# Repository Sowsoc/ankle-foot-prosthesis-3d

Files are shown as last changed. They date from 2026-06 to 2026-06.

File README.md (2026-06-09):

# Prótese funcional de pé-tornozelo articulada (impressa em 3D, baixo custo)

**Disciplina:** Dispositivos de Reabilitação — Eng. Biomédica, FUMEC
**Entrega:** 22/06/2026 — produto físico + relatório técnico + apresentação formal
**Natureza:** trabalho dedicado e independente

---

## Decisões de projeto (travadas em 06/06)

| Eixo | Decisão | Razão |
|---|---|---|
| Origem do design | **Remixar open-source** | Prazo de 16 dias; partir de base comprovada e justificar mudanças é mais defensável que do zero |
| **Design-base** | **A — Make3D "Prosthetic Foot Prototype" (Printables #293133)** | Votado pelo grupo em 08/06; maior score (4,2/5), single-axis direto, conector de pylon integrado. Arquivos em `cad/A_make3d_293133/` |
| **Conector de pylon** | **Insert custom do design-base (Opção A)** | Votado pelo grupo em 09/06; conector retangular 26×14×46 mm integrado ao modelo — adequado para demonstração acadêmica, sem peça comprada extra |
| Alvo dimensional | **Genérico adulto padrão** | Sem dependência de medir paciente; protótipo demonstrativo |
| Articulação | **Single-axis (dorsi/plantarflexão)** | Mais simples de modelar e imprimir; clássico e suficiente para "funcional" |
| Régua de avaliação | **Briefing livre → régua proposta abaixo** | Não há enunciado escrito do professor |

---

## Requisitos / especificações alvo

Usuário de projeto: **adulto ~70 kg, pé ~26–27 cm (BR 40–41)**.

| Requisito | Valor alvo | Observação |
|---|---|---|
| Carga estática de projeto | ≥ 1,5 × peso corporal ≈ **1030 N** | Pico de heel-strike na marcha normal é ~1,2–1,5× BW |
| Fator de segurança | **2–3** → dimensionar p/ ~2–3 kN | Literatura: FEA achou tensão máx. **15 MPa no heel-strike a 150% BW** |
| ADM dorsiflexão | **10–15°** | Limitada por batente elástico anterior |
| ADM plantarflexão | **15–20°** | Limitada por batente elástico posterior |
| Conexão proximal | Adaptador de pylon padrão (pirâmide 30 mm) ou simplificado | Depende do que o design-base oferece |
| Custo de material | **< R$ 200** | Filamento + parafuso/bucha + TPU. Comparar com prótese comercial (US$ 5k–50k) |
| Massa | minimizar (alvo informativo) | Trade-off com rigidez |

### Materiais previstos
- **Estrutura/keel:** PETG (tenaz, melhor fadiga/impacto que PLA) ou PLA-CF (mais rígido). **Evitar PLA puro** sob carga cíclica — frágil, falha por fadiga.
- **Eixo da articulação:** parafuso de aço M8 + bucha (nylon/bronze).
- **Batentes (bumpers) dorsi/plantar:** TPU ~95A — definem a ADM e amortecem.
- **Orientação de impressão (CRÍTICO):** carga principal deve solicitar o **mínimo possível** a adesão entre camadas (eixo Z é o ponto fraco do FDM). Imprimir o keel deitado.

---

## Régua de avaliação (proposta — briefing livre)

Como não há enunciado, esta é a régua que vou usar para guiar o relatório/apresentação. Ajuste se o professor sinalizar critério diferente.

1. **Produto físico funcional** — articulação se move na ADM alvo e suporta a carga de demonstração. *(peso maior)*
2. **Relatório técnico completo** — ver `RELATORIO.md`.
3. **Fundamentação biomecânica** — ciclo de marcha, papel do tornozelo, justificativa da articulação single-axis vs SACH.
4. **Justificativa de engenharia** — escolha de material, orientação de impressão, geometria, com trade-offs explícitos.
5. **Validação** — teste de ADM medido, teste de carga (mesmo qualitativo), fotos/vídeo. Ver `testes/`.
6. **Baixo custo demonstrado** — planilha de custo real vs. alternativa comercial.
7. **Apresentação formal** — domínio do tema, defesa dos trade-offs sob arguição.

---

## Candidatos open-source para remixar

| Candidato | Articulação | Prós | Contras |
|---|---|---|---|
| **Make3D "Prosthetic Foot Prototype"** (Printables 293133) | Pino + mola, dedos flexíveis, conector de pylon | Match mais direto; STL grátis; feito em Fusion 360 (editável) | **Não testado**; usa Filaflex40 + mola |
| **Appropedia "3D printed prosthetic foot"** | Snap-fit + amortecedor ball-joint | Open source de verdade; ~4% do custo comercial; simples | Estágio "infância"; pouca validação |
| **Colorado School of Mines Capstone** | Flex-ankle (dobradiça flexível), passivo | Pensado p/ ABS / PETG-nylon; manual de instruções | Pediátrico; precisa reescalar |

**Recomendação:** começar pela **Make3D (Printables)** como base estrutural single-axis e simplificar a mola para batentes TPU (mais imprimível, menos dependência de peça comprada). Baixar o STL/CAD para `cad/` e `refs/`.

Referências acadêmicas para fundamentar o relatório (salvar PDFs em `refs/`):
- Baseline não-articulado: **SACH** (solid-ankle cushion-heel) — comparar contra ele.
- FEA de pé protético: tensão máx. 15 MPa @ 150% BW; recurso de projeto = **split forefoot/heel**.
- Toe joint com rigidez não-linear (Nature Sci. Reports) — se for modelar antepé flexível.
- Composites: PLA/fibra de carbono supera PLA puro em desempenho/peso.

Links em `refs/FONTES.md`.

---

## Riscos (ordem de severidade)

1. **Acesso à impressora 3D** — gargalo absoluto. Um pé inteiro são muitas horas/peça + chance de falha. *Se depende do lab da FUMEC, agendar AGORA.* ⛔ bloqueante.
2. **Falha estrutural por orientação/material** — camada Z fraca. Mitigação: PETG, orientação correta, infill 40%+, parede grossa.
3. **Colisão com o estágio (início 15/06)** — janela de impressão encolhe. Travar CAD até 14/06.
4. **Articulação (pino/folga/batente)** — ponto de movimento = ponto de desgaste/folga. Prototipar a junta isolada antes da peça inteira.

---

## Estrutura de pastas

- `cad/` — arquivos editáveis (Fusion/FreeCAD/STEP)
- `stl/` — malhas prontas para fatiar
- `slicing/` — perfis e .gcode/.3mf, parâmetros de impressão
- `refs/` — design-base baixado, PDFs de referência, `FONTES.md`
- `fotos/` — registro de fabricação/montagem/testes (para o relatório)
- `testes/` — dados de ADM e carga, planilha de custo
- `RELATORIO.md` — relatório técnico (em construção)
- `PLANO.md` — cronograma de 16 dias e caminho crítico

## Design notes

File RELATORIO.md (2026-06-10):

# Relatório técnico — Prótese funcional de pé-tornozelo articulada (3D, baixo custo)

> Disciplina: Dispositivos de Reabilitação — FUMEC · Autor: João Vítor Silva Oliveira · Entrega: 22/06/2026
> Esqueleto. Cada seção lista o que precisa conter. `[ ]` = a preencher. As decisões de
> engenharia, o CAD e a validação são trabalho seu — este arquivo é o mapa, não o conteúdo.

## Resumo (abstract)
- [ ] 1 parágrafo: o que é, decisão single-axis, material, custo, principal resultado de validação.

## 1. Introdução

### 1.1 Problema

A amputação de membro inferior impõe ao indivíduo a dependência de uma prótese para restaurar a marcha. O componente pé-tornozelo é determinante para a qualidade dessa marcha — é ele que faz o contato com o solo, absorve o impacto do heel-strike e devolve energia no push-off. Próteses de pé-tornozelo comerciais funcionais, contudo, custam tipicamente de **US$ 5.000 a US$ 50.000** [MDPI Machines 10(6):413], valor proibitivo em contextos de baixa renda e sistemas públicos de saúde sobrecarregados. O resultado é um déficit global de acesso: a OMS estima que apenas uma fração das pessoas que necessitam de próteses tem acesso a elas.

A manufatura aditiva (impressão 3D FDM) abriu uma via para reduzir radicalmente esse custo. Designs open-source de pés protéticos imprimíveis relatam custo de material em torno de **4 % do equivalente comercial** [Appropedia; MDPI Machines 10(6):413], ao preço de menor validação estrutural e durabilidade. O desafio de engenharia é claro: entregar mobilidade de tornozelo e resistência estrutural suficientes com filamento de baixo custo e um processo (FDM) intrinsecamente anisotrópico.

### 1.2 Distinção prótese × órtese

Convém fixar o termo, dado que a disciplina trata dos dois dispositivos. **Órtese** é um dispositivo que *assiste ou corrige* um segmento corporal existente (ex.: uma AFO — ankle-foot orthosis — que apoia um tornozelo fraco). **Prótese** *substitui* um segmento ausente. Este trabalho é uma **prótese**: substitui o pé-tornozelo de um amputado, não auxilia um membro presente.

### 1.3 Objetivo e escopo

O objetivo é projetar, fabricar e validar um **protótipo funcional de pé-tornozelo protético articulado**, impresso em 3D (FDM) a baixo custo, com mobilidade real de tornozelo (mecanismo single-axis), partindo do remix de um design open-source e justificando cada decisão de engenharia.

**Escopo e fronteiras:**
- Trata-se do **módulo pé-tornozelo** de uma prótese **transtibial** (abaixo do joelho) modular. O encaixe (cartucho moldado ao coto, paciente-específico) e o pylon (tubo padronizado) são componentes *upstream* fora do escopo — o projeto entrega a peça que se conecta ao pylon.
- Usuário de projeto genérico: adulto ~70 kg, pé 26-27 cm (BR 40-41), **marcha em superfície plana**. Corrida e terreno irregular estão fora do escopo.
- **Dispositivo de demonstração acadêmica — não clínico.** Nenhum protótipo deste trabalho deve receber carga corporal real sem validação mecânica formal (ensaio de fadiga/ciclagem) e avaliação de protético certificado. A validação aqui é qualitativa/demonstrativa (amplitude de movimento e teste de carga estática), não uma certificação de uso.

### 1.4 Organização do relatório

A seção 2 fundamenta a biomecânica do tornozelo na marcha e as cargas de projeto; a seção 3 fecha os requisitos de engenharia; a seção 4 descreve a concepção e as alterações sobre o design-base; a seção 5 trata de materiais, dimensionamento estrutural e fabricação; as seções 6 a 8 apresentam a validação, o custo e a discussão; a seção 9 conclui.

## 2. Fundamentação biomecânica

### 2.1 Ciclo da marcha e papel do tornozelo

O ciclo da marcha divide-se em fase de apoio (stance, ~60% do ciclo) e fase de balanço (swing, ~40%). O tornozelo cumpre três funções biomecânicas críticas durante o apoio [PMC4994968]:

1. **Heel-strike / loading response (0–12% do ciclo):** ao toque do calcanhar, a GRF impõe carga de impacto. O tornozelo entra em plantarflexão rápida (~5–10°) enquanto os dorsiflexores (tibial anterior) desaceleram o pé. Este é o pico de carga estrutural sobre a prótese.

2. **Midstance (10–30%):** o corpo avança sobre o pé fixo; o tornozelo funciona como pivot. GRF vertical ≈ 1,0–1,2 × PC.

3. **Push-off / toe-off (40–60%):** plantarflexão ativa (~20°) pelo tríceps sural impulsiona o corpo para frente. Em prótese passiva, batentes elásticos (TPU) absorvem parte da energia de retorno.

### 2.2 Amplitude de movimento fisiológica na marcha

| Movimento | Valor fisiológico | Alvo do protótipo |
|---|---|---|
| Dorsiflexão | 10–15° [1] | 10–15° — batente anterior TPU |
| Plantarflexão | 15–20° [1] | 15–20° — batente posterior TPU |
| ADM total sagital na marcha | ~25–35° [1] | 25–35° |

[1] Síntese de: OrthoFixar — Ankle Range of Motion; Meloq Devices — Normal Ankle ROM; Biomechanics of the ankle — PMC4994968.

### 2.3 Por que articular: SACH vs. single-axis

A prótese SACH (solid-ankle cushion-heel) é o baseline não-articulado mais difundido — baixo custo, zero manutenção, mas sem mobilidade real de tornozelo:

| Critério | SACH | Single-axis (este projeto) |
|---|---|---|
| ADM | 0° (rígida) | 10–15° dorsi / 15–20° plantar |
| Absorção de choque | calcanhar em espuma | batente TPU dorsal absorve heel-strike |
| Adaptação a terreno | limitada | parcial — ADM absorve variação de inclinação |
| Custo / complexidade | mínimos | baixo — eixo M8 + batentes TPU |

A articulação single-axis é a escolha mínima viável que confere mobilidade real sem a complexidade de sistemas multi-eixo ou ESAR (energy-storing-and-return em carbono), inviáveis no prazo e custo deste projeto.

### 2.4 Cargas na seção crítica (heel-strike)

GRF vertical de pico na marcha normal: **1,0–1,5 × PC** [Nilsson & Thorstensson, Acta Physiol Scand 1989, PMID 2782094]. Para o usuário de projeto (70 kg):

- **Carga de projeto: P = 1,5 × 70 × 9,81 ≈ 1030 N** (extremo conservador da marcha plana)
- Referência de sanidade: FEA de pé protético acha tensão máx. ~15 MPa no heel-strike a 150% PC [ResearchGate 318989655] — mesma ordem do dimensionamento preliminar (ver seção 5).
- Escopo: marcha em superfície plana. Corrida (pico 2,0–2,9 × PC) está fora do escopo deste protótipo acadêmico.

## 3. Requisitos de projeto

**Usuário de projeto:** adulto genérico, ~70 kg, pé 26–27 cm (BR 40–41), marcha em superfície plana.

| Requisito | Valor alvo | Justificativa |
|---|---|---|
| Carga estática de projeto | ≥ 1030 N (= 1,5 × BW) | GRF de pico na marcha normal é 1,0–1,5 × BW [Nilsson & Thorstensson, PMID 2782094]; extremo superior = conservador |
| Fator de segurança | 2–3 (FS = 2,5 adotado) | Faixa padrão para dispositivos com carga dinâmica e fabricação FDM (variabilidade de processo elevada) |
| ADM dorsiflexão | 10–15° | Mínimo para marcha eficiente sem compensação proximal [PMC4994968]; definida por batente TPU anterior |
| ADM plantarflexão | 15–20° | Necessário para push-off e descida [PMC4994968]; definida por batente TPU posterior |
| Conexão proximal | Adaptador pylon pirâmide 30 mm ou simplificado | Padrão ISO 22523; depende do design-base escolhido |
| Custo de material | < R$ 200 | PETG (~250 g × R$ 120/kg ≈ R$ 30) + TPU + M8 + bucha; comparar com SACH comercial (US$ 5k–50k) |
| Massa | minimizar (alvo informativo) | Trade-off com rigidez; aceito no escopo acadêmico |
| Material estrutural | PETG (keel) + TPU ~95A (batentes) + M8 aço 8.8 (eixo) | Justificativa completa em seção 5 e `testes/dimensionamento.py` |
| Orientação de impressão | Keel deitado (carga no plano XY) | Anisotropia Z do FDM reduz resistência 30–50% [OSTI 1808415]; orientar para máxima resistência no plano — ver seção 5 |

## 4. Concepção e projeto (design)

### 4.1 Estratégia: remix de design open-source

Dado o prazo de 16 dias e a régua de "produto funcional defensável", optou-se por **remixar um design open-source comprovado** em vez de modelar do zero. Partir de uma base existente e justificar cada alteração de engenharia é mais defensável — e mais honesto sobre o esforço real — do que reivindicar um projeto original mal validado.

O design-base foi selecionado por matriz de decisão ponderada (ver `refs/decisao_design_base.md`), com critérios de imprimibilidade FDM, robustez, facilidade de edição, aderência ao mecanismo single-axis e licença. Venceu o **Make3D "Prosthetic Foot Prototype"** (Printables #293133, licença CC BY-NC-SA), com score 4,2/5, por oferecer articulação single-axis direta, conector de pylon integrado e a maior comunidade de remix.

**Limitação assumida:** o autor publicou apenas malhas STL — não há arquivo CAD paramétrico (Fusion 360/STEP) oficial. A adaptação foi feita, portanto, por **edição de malha** (script reproduzível em `cad/A_make3d_293133/processar_pecas.py`, biblioteca `trimesh`), e não por modelagem paramétrica. Isso restringe o tipo de alteração possível (escala e operações booleanas, não re-parametrização de features), mas é suficiente para as três mudanças que o projeto exige.

### 4.2 Componentes do design-base e papéis

| Peça (STL nativo) | Papel | Material no remix |
|---|---|---|
| `InnerFoot` | Keel — quilha estrutural; carrega a flexão do heel-strike | PETG |
| `TopJoint` | Junta superior do tornozelo; aloja o eixo de pivô | PETG |
| `FootRubber` | Sola / antepé flexível | TPU 95A |
| `RubberCube` | Batente elástico (define a ADM e amortece) | TPU 95A |
| `Insert` | Conector proximal ao pylon | PETG |

> **Escopo:** este trabalho desenvolve o **módulo pé-tornozelo** de uma prótese **transtibial** modular. O encaixe (cartucho moldado ao coto, paciente-específico) e o pylon (tubo padronizado) são componentes *upstream* fora do escopo — representados apenas em diagrama. O `Insert` é a interface física com o pylon.

### 4.3 Alterações de engenharia (o que mudou e por quê)

Três modificações sobre o design-base, todas defensáveis:

**1. Escala ×1,262 do casco (pé ~21 cm → 26-27 cm).**
O modelo nativo tem pé de 209,9 mm (≈ BR 33), abaixo do usuário de projeto (adulto, pé 26-27 cm, BR 40-41). Aplicou-se escala uniforme de 1,262 às peças do casco (keel, sola, conector, batente). O `TopJoint` foi **mantido em escala nativa** (ver alteração 2). A escala, além de atender ao requisito dimensional, **reduz a tensão estrutural**: como σ_flexão ∝ (P·L)/(B·H²), escalar todas as dimensões por *s* faz σ variar com 1/*s²* — escalar para o alvo melhora a margem em ~37 % (ver seção 5 e `testes/dimensionamento.py`).

**2. Normalização do eixo da articulação para M8.**
O design nativo usa dois diâmetros distintos no mesmo eixo de pivô: furo Ø4,8 mm (≈ passagem de M5) no keel e bore Ø10,0 mm no `TopJoint`. Nenhum corresponde ao eixo M8 8.8 dimensionado na seção 5. A solução:
- **Keel:** furo aberto de Ø4,8 → **Ø8,4 mm** (folga de M8), via operação booleana concêntrica ao eixo nativo.
- **TopJoint mantido nativo:** o bore Ø10,0 mm casa **exatamente** com uma **bucha de nylon comercial 10×8** (OD 10 / ID 8). Manter o `TopJoint` sem escala preserva esse encaixe de prateleira — escalá-lo levaria o bore a Ø12,7 mm e exigiria ferragem fora de padrão. A bucha funciona como mancal do parafuso M8, eliminando o contato direto aço-plástico (o esmagamento do furo no plástico, *bearing*, é o elo estrutural mais fraco da junta — seção 5).

**3. Substituição dos elementos elásticos por TPU 95A impresso.**
O design original previa Filaflex/mola para os elementos compressíveis. No remix, o batente (`RubberCube`, envelope 22,85 × 19,04 × 28 mm) é reproduzido em **TPU 95A**, dispensando peça comprada. A dureza Shore 95A não é cosmética: é o parâmetro que define a rigidez do batente e, com ela, a amplitude de movimento — batente anterior limita a dorsiflexão (10-15°), posterior limita a plantarflexão (15-20°).

### 4.4 Mecanismo single-axis resultante

A articulação final é um **eixo único** (parafuso M8 classe 8.8) atravessando o keel (furo Ø8,4) e a junta superior, apoiado em bucha de nylon 10×8 no bore do `TopJoint`. O movimento de dorsi/plantarflexão ocorre em torno desse eixo no plano sagital; os batentes de TPU 95A definem os limites angulares e absorvem energia. É a escolha mínima viável que confere mobilidade real de tornozelo sem a complexidade de sistemas multi-eixo ou ESAR (energy-storing-and-return em carbono), inviáveis no prazo e custo (comparação SACH × single-axis na seção 2.3).

**Ferragem de montagem:** 1× parafuso M8 × 60 mm cl. 8.8 (eixo), 2× bucha nylon 10×8 (mancal), 1× porca M8 autotravante + arruelas de nylon (reduzem atrito entre faces).

### 4.5 Arquivos gerados

STLs finais nomeados por peça em `stl/` (`keel_petg`, `tornozelo_superior_petg`, `sola_tpu`, `conector_pylon_petg`, `batente_tpu`), parâmetros de fabricação em `slicing/ESPECIFICACOES_IMPRESSAO.md`, e preview em `stl/preview_pecas.png`. *(Renders/fotos finais do CAD a inserir aqui.)*

## 5. Materiais e fabricação

### 5.1 Material por componente

| Componente | Material | Justificativa |
|---|---|---|
| Keel / corpo estrutural | **PETG** (infill ≥ 50%, ≥ 4 perímetros) | Tenaz e dúctil: absorve impacto sem fratura frágil; melhor adesão entre camadas que PLA puro e PLA-CF sob carga cíclica; UTS impresso ~40–45 MPa no plano XY [MDPI Polymers 11(7):1220; PMC12694470] |
| Batentes dorsi/plantar | **TPU ~95A** | Define a ADM e absorve energia do heel-strike; imprimível por FDM; 95A = compromisso entre amortecimento e estabilidade |
| Eixo da articulação | **Parafuso M8 classe 8.8** | Aço, UTS 800 MPa, A_s = 36,6 mm², τ_adm = 480 MPa; o eixo é superdimensionado (FS real ≈ 34×) — o elo crítico é o **furo no plástico** (bearing), não o parafuso |
| Bucha do furo | Nylon ou bronze (recomendado) | Distribui tensão de bearing no furo; reduz desgaste em movimento cíclico |

**Por que PETG e não PLA-CF?**
PLA reforçado com fibra de carbono picada parece mais rígido (E ≈ 3 GPa vs 1 GPa do PETG), mas: (1) UTS impresso pode ser *menor* que PLA puro (~17–28 MPa vs ~40–45 MPa do PETG) pela fusão inter-filamento pior com fibra [Oxford Acad. MAM 29 S1:1447]; (2) a fibra agrava a anisotropia Z — Z pode cair 80–90% vs XY [OSTI 1808415]. PETG bem orientado com k_z = 0,50 entrega σ_adm ≈ 9 MPa; PLA-CF com k_z = 0,40 entrega 6,1 MPa, exigindo parede quase 2,5× mais grossa. PETG ganha em tenacidade, previsibilidade e imprimibilidade.

### 5.2 Parâmetros de impressão (recomendados)

| Parâmetro | Valor | Razão |
|---|---|---|
| **Orientação do keel** | **Deitado** (eixo longo horizontal) | Flexão solicita o plano XY — o mais resistente; imprimir vertical coloca carga no eixo Z (adesão entre camadas), 30–50% mais fraco [OSTI 1808415] |
| Perímetros | **≥ 4–6** (linha 0,4 mm → 1,6–2,4 mm) | Flexão é carregada pelas paredes externas, não pelo infill; mais perímetros = maior I da seção |
| Infill | **≥ 50%, padrão giroide** | Giroide é isotrópico, imprime sem suporte interno, resiste a cisalhamento; 100% só agrega massa sem ganho proporcional em flexão |
| Layer height | 0,2 mm | Melhor fusão interlaminar; balanço com tempo de impressão |
| Temperatura bico PETG | 230–240 °C | Limite superior da faixa melhora adesão Z [MDPI Polymers 11(7):1220] |
| Temperatura mesa | 70–80 °C | Previne warping em peças longas de PETG |
| Suportes | Mínimos; interface com gap 0,2 mm | Keel deitado minimiza necessidade; usar só na região do furo do eixo |

### 5.3 Dimensionamento estrutural preliminar

> Script reproduzível: `testes/dimensionamento.py` — gráficos em `testes/dimensionamento_flexao.png` e `testes/dimensionamento_materiais.png`.
> Geometria **medida** no STL do design-base A (Make3D #293133), keel = `InnerFoot.stl`.

**Parâmetros de entrada (medidos no STL de A):**
- Carga de projeto: P = 1030 N (1,5 × 70 kg × 9,81 m/s²)
- Seção crítica medida (região do tornozelo, ~55 mm do calcanhar): B = 43 mm, H = 37 mm
- Momento fletor na seção crítica: M = P × L = 1030 × 55 ≈ 56 700 N·mm (L = 55 mm medido)
- Modelo: viga em flexão, seção retangular oca (casca); infill desprezado (conservador — a favor da segurança)
- **Escala:** keel nativo do modelo (pé ~21 cm) é menor que o alvo 26–27 cm. Os cálculos usam a escala **nativa (pior caso)**; escalar ao alvo (×~1,26) só aumenta a margem (σ ∝ 1/escala², pois o módulo de seção cresce ∝ escala³ enquanto o braço cresce ∝ escala).

**Resultados (FS = 2,5):**

| Material | UTS_xy [MPa] | k_z [-] | σ_adm [MPa] | t_min casca [mm] |
|---|---|---|---|---|
| PETG | 45 | 0,50 | 9,0 | 4,3 |
| PLA-CF | 38 | 0,40 | 6,1 | 10,1 |

Sanity-check: tensão na seção sólida equivalente = 5,8 MPa — mesma ordem do FEA de literatura (~15 MPa @150% PC [ResearchGate 318989655]), com folga.

**Articulação — eixo M8 8.8 (junta dupla, 2 planos de cisalhamento):**
- τ atuante = 14,1 MPa → FS real do pino ≈ **34×** — superdimensionado, não é o elo fraco
- σ_bearing admissível no furo (PETG): 20,8 MPa → espessura mínima de material ao redor do furo ≈ **6,2 mm**
- **Elo crítico: esmagamento (bearing) do furo no plástico** → mitigar com bucha metálica e material generoso ao redor do eixo

**Recomendação consolidada:** PETG para keel (t_min 4,6 mm, tenacidade, anisotropia Z aceitável com orientação correta), TPU ~95A para batentes, M8 8.8 para eixo com bucha metálica obrigatória no furo.

### 5.4 Tempo e consumo de filamento

> A preencher com dados do slicer após CAD travado (etapa 15/06 — ver `PLANO.md`).

## 6. Validação / testes
- [ ] Teste de ADM: medir dorsi/plantarflexão real vs alvo (transferidor/foto).
- [ ] Teste de carga: aplicar carga conhecida, observar deformação/falha (qualitativo já vale).
- [ ] Registro fotográfico/vídeo (de `fotos/`).

## 7. Custo
- [ ] Planilha: filamento (g × R$/kg) + parafuso/bucha + TPU = total. Comparar com comercial.

## 8. Resultados e discussão
- [ ] O que funcionou, o que falhou, o que reimprimiria. Limitações (FDM, sem ciclagem de fadiga, etc.).

## 9. Conclusão
- [ ] Atingiu os requisitos? Trade-offs centrais. Próximos passos.

## Referências
- [ ] Ver `refs/FONTES.md` + livro-texto da disciplina. Formatar ABNT.

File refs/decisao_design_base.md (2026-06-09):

# Matriz de decisão - design-base para remix

> Decisão do grupo (06/06/2026): dois candidatos principais + plano B.

---

## Candidatos

| ID | Projeto | Link | Papel |
|----|---|---|---|
| A | Make3D - Prosthetic Foot Prototype | [Printables #293133](https://www.printables.com/model/293133-prosthetic-foot-prototype) | ✅ Principal |
| D | Prosthetic Foot-Ankle for 3D Printing | [Printables #1032352](https://www.printables.com/model/1032352-prosthetic_foot-ankle-for-3d-printing) | ✅ Principal |
| B | Appropedia - 3D printed prosthetic foot | [Appropedia](https://www.appropedia.org/3D_printed_prosthetic_foot) | ⚠ Plano B (página instável) |

---

## Critérios e pesos

| # | Critério | Peso |
|---|---|---|
| 1 | Imprimibilidade FDM (sem material exótico, sem suporte excessivo) | 25% |
| 2 | Robustez estrutural / documentação de carga | 20% |
| 3 | Facilidade de remix / edição CAD (formato editável, licença) | 25% |
| 4 | Aderência ao mecanismo single-axis (dorsi/plantarflexão com eixo) | 20% |
| 5 | Licença (uso acadêmico, derivação, publicação) | 10% |

Pontuação: 1 (mínimo) a 5 (máximo). Score = Σ(peso × nota).

---

## Pontuação detalhada

### A - Make3D / Printables #293133

| Critério | Nota | Justificativa |
|---|---|---|
| Imprimibilidade FDM | 4 | STL pronto; Filaflex40 substituível por TPU; mola substituível por batente impresso |
| Robustez estrutural | 3 | Geometria de keel com pino em Fusion 360; sem teste de carga documentado |
| Remix / edição CAD | 5 | Fusion 360, STEP/F3D exportável, maior comunidade de remix |
| Single-axis | 5 | Match direto: pino + articulação; conector de pylon padrão já incluído |
| Licença | 4 | CC BY-NC-SA Printables; uso acadêmico OK |
| **Score ponderado** | **4,2** | |

**O que aproveitar:** geometria do keel, mecanismo de articulação (furo + flange para M8), conector de pylon.
**O que alterar:** Filaflex/mola → batentes TPU impressos; ajustar espessura de parede conforme dimensionamento.py; reescalar para pé 26-27 cm se necessário.

### D - Printables #1032352

| Critério | Nota | Justificativa |
|---|---|---|
| Imprimibilidade FDM | 4 | PETG + TPU 65A nativos; sem material exótico; partes de reposição rápidas |
| Robustez estrutural | 3 | Testado pelo autor; resistente a água/poeira; sem documentação de carga formal |
| Remix / edição CAD | 3 | Disponível no Printables; formato CAD editável a confirmar antes de baixar |
| Single-axis | 4 | Articulação de tornozelo funcional + flexão em calcanhar e dedos; próximo do single-axis |
| Licença | 4 | CC BY-NC-SA Printables; uso acadêmico OK |
| **Score ponderado** | **3,65** | |

**O que aproveitar:** material nativo PETG+TPU já alinhado; articulação de tornozelo funcional; simplicidade de fabricação.
**O que alterar:** confirmar/ajustar mecanismo para single-axis puro com eixo M8; verificar formato CAD editável.

### B - Appropedia (plano B)

| Critério | Nota | Justificativa |
|---|---|---|
| Imprimibilidade FDM | 3 | Snap-fit + ball-joint pode ser problemático em FDM sem ajuste de tolerância |
| Robustez estrutural | 2 | "Estágio infância" per documentação; pouca validação |
| Remix / edição CAD | 3 | Arquivos disponíveis mas formato menos maduro |
| Single-axis | 2 | Ball-joint ≠ single-axis; exige reformulação do mecanismo |
| Licença | 5 | CC BY-SA; sem restrição comercial |
| **Score ponderado** | **2,85** | |

Usar só se A e D forem inviáveis. Exige redesign do mecanismo de articulação.

---

## Resumo comparativo

| | A - Make3D #293133 | D - #1032352 | B - Appropedia |
|---|---|---|---|
| Score ponderado | **4,2** | 3,65 | 2,85 |
| Papel | Principal | Principal | Plano B |
| Maior força | Single-axis + CAD editável | PETG+TPU nativo | Licença aberta |
| Maior fraco | Sem teste de carga | Formato CAD incerto | Página instável + mecanismo diferente |

---

## Próximos passos

1. Baixar STL + STEP/F3D de A e D para `cad/`
2. Abrir ambos no FreeCAD/Fusion e comparar geometria do tornozelo
3. Escolher qual serve de base principal para o remix (ou combinar elementos dos dois)
4. Medir B, H, L do keel no design escolhido e rodar `testes/dimensionamento.py` com valores reais

---

> *Decisão registrada em 06/06/2026.*

---

## ✅ VEREDITO (08/06/2026)

**Vencedor: A — Make3D / Printables #293133.** Decidido por votação do grupo.
Razão: maior score (4,2), articulação single-axis direta e conector de pylon já
integrado — menor trabalho de CAD no prazo apertado.

**Status pós-download:**
- STLs baixados e versionados em `cad/A_make3d_293133/` (InnerFoot, FootRubber, TopJoint, Insert, RubberCube) + PDF em `refs/A_make3d_293133/`.
- Keel estrutural = `InnerFoot.stl`. Seção crítica medida (B=43, H=37, L=55 mm) → `dimensionamento.py` re-rodado: **PETG t_parede ≈ 4,3 mm** com FS 2,5.
- ⚠ **Ressalvas a tratar no CAD:** (1) pacote de A **não traz STEP/F3D** — só STL; remix exige edição de malha (Blender) ou baixar o F3D no Printables. (2) **Escala:** pé do modelo ~21 cm < alvo 26–27 cm → escalar ~1,26× (favorável à estrutura).

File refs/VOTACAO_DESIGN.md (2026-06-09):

# Votação - Design-base da Prótese

**Projeto:** Prótese funcional pé-tornozelo articulada, single-axis, 3D FDM, baixo custo
**Disciplina:** Dispositivos de Reabilitação - FUMEC - Entrega: 22/06/2026
**Decisão necessária:** qual design remixar como base estrutural

> Votar até: definir com o grupo. Após votação, registrar no README e baixar os arquivos.

---

## Contexto do projeto

| Item | Definição |
|---|---|
| Tipo de dispositivo | Prótese transtibial de pé-tornozelo (substitui segmento ausente) |
| Mecanismo | Single-axis: 1 eixo de rotação, dorsi/plantarflexão com batentes elásticos |
| Usuário de projeto | Adulto ~70 kg, pé 26-27 cm (BR 40-41), marcha em superfície plana |
| Carga de projeto | 1.030 N (1,5 × peso corporal - pico do heel-strike) |
| Fator de segurança | 2,5 |
| Material definido | PETG (estrutura) + TPU 95A (batentes) + parafuso M8 aço (eixo) |
| Custo-alvo | < R$ 200 em material |
| Abordagem | Remixar design open-source existente - não partir do zero |
| Impressão | Terceirizada - enviar STLs + especificações até 13/06 |

---

## Opção A - Make3D Prosthetic Foot Prototype
**Link:** https://www.printables.com/model/293133-prosthetic-foot-prototype
**Score técnico:** 4,2 / 5,0

### O que é
Prótese de pé transtibial com articulação de tornozelo, dedos flexíveis e conector de pylon padrão. Desenvolvida pela Make3D em Fusion 360, disponível em STL e STEP/F3D exportável. Projeto com maior comunidade de remix no Printables.

### Articulação
Single-axis com pino metálico + mola (ou Filaflex40). A mola/Filaflex será substituída por batentes de TPU impressos - única adaptação de concepção necessária.

### Materiais (original / nosso remix)

| Peça | Original | Remix proposto |
|---|---|---|
| Keel / estrutura | PLA ou PETG | PETG (infill ≥ 40%, paredes ≥ 3) |
| Dedos / antepé flexível | Filaflex 40A | TPU 95A |
| Batentes dorsi/plantar | Mola metálica comprada | TPU 95A impresso |
| Eixo da articulação | Parafuso | Parafuso M8 aço 8.8 + bucha nylon |
| Conector de pylon | Integrado ao design | Manter (pirâmide 30 mm padrão) |

### Custo estimado (remix)

| Item | Qtd | Custo estimado |
|---|-----|---|
| PETG 1kg (Polymaker, Bambu etc.) | ~200-250g | R$ 25-35 |
| TPU 95A 1kg | ~50-80g | R$ 10-15 |
| Parafuso M8 × 60mm aço 8.8 | 1 | R$ 3-5 |
| Porca M8 + arruelas | 2-4 | R$ 2-4 |
| Bucha nylon M8 | 1 | R$ 3-5 |
| **Total estimado** | | **R$ 43-64** |

*Comparativo: prótese comercial equivalente = US$ 5.000-50.000 (R$ 25.000-250.000)*

### Prós
- Maior score técnico (4,2/5)
- Match direto com single-axis - menor trabalho de CAD
- CAD editável em Fusion 360 (STEP/F3D exportável)
- Conector de pylon padrão já integrado
- Maior comunidade de remix e referências

### Contras
- Sem teste de carga documentado pelo autor
- Filaflex40 original exige troca por TPU (simples, mas é alteração)
- Verificar escala para pé 26-27 cm

---

## Opção D - Prosthetic Foot-Ankle for 3D Printing
**Link:** https://www.printables.com/model/1032352-prosthetic_foot-ankle-for-3d-printing
**Score técnico:** 3,65 / 5,0

### O que é
Prótese de pé-tornozelo projetada para ser acessível, simples de produzir e resistente a água/poeira. Material nativo já é PETG + TPU - alinhamento direto com as decisões do projeto. Testada pelo autor.

### Articulação
Articulação de tornozelo com movimento similar ao humano + flexão em calcanhar e dedos. Mecanismo próximo do single-axis; confirmar se usa eixo rígido ou dobradiça flexível após baixar o CAD.

### Materiais (original / nosso remix)

| Peça | Original | Remix proposto |
|---|---|---|
| Keel / estrutura | PETG | PETG (manter - já alinhado) |
| Tendões / flexão | TPU 65A | TPU 95A (ajuste de dureza) |
| Batentes dorsi/plantar | TPU (integrado) | TPU 95A impresso (manter conceito) |
| Eixo da articulação | A confirmar | Parafuso M8 aço 8.8 + bucha nylon |
| Conector de pylon | A confirmar | Adaptar ao projeto |

### Custo estimado (remix)

| Item | Qtd | Custo estimado |
|---|-----|---|
| PETG 1kg | ~200-250g | R$ 25-35 |
| TPU 95A 1kg | ~80-100g | R$ 15-20 |
| Parafuso M8 + porca + arruelas | - | R$ 5-9 |
| Bucha nylon M8 | 1 | R$ 3-5 |
| **Total estimado** | | **R$ 48-69** |

*Comparativo: prótese comercial equivalente = US$ 5.000-50.000 (R$ 25.000-250.000)*

### Prós
- PETG + TPU nativos - zero troca de material
- Testada pelo autor em condições reais
- Resistente a água e poeira (durabilidade)
- Simples de produzir e repor peças

### Contras
- Score menor (3,65/5) principalmente por incerteza no formato CAD
- Formato editável (STEP/F3D) a confirmar antes de baixar
- Mecanismo de articulação a detalhar - pode exigir mais adaptação

---

## Opção B - Appropedia (plano B)
**Link:** https://www.appropedia.org/3D_printed_prosthetic_foot
**Score técnico:** 2,85 / 5,0
**Status: página instável - usar só se A e D forem inviáveis**

### O que é
Design open-source OSAT (appropriate technology) de código aberto completo. Articulação snap-fit com amortecedor ball-joint. Custo muito baixo (~4% do comercial). Projeto em estágio inicial conforme documentação.

### Articulação
Snap-fit + ball-joint (amortecedor). Mecanismo diferente do single-axis definido - exigiria redesign completo da região do tornozelo para adaptar ao eixo M8.

### Materiais

| Peça | Material |
|---|---|
| Pé + perna | PLA ou PETG |
| Articulação | Snap-fit impresso |
| Amortecedor | Ball-joint impresso |

### Custo estimado

| Item | Custo estimado |
|---|---|
| PETG ~200g | R$ 25-30 |
| Hardware mínimo | R$ 5-10 |
| **Total estimado** | **R$ 30-40** |

### Prós
- Licença mais aberta (CC BY-SA, sem restrição comercial)
- Menor custo de material
- Filosofia open-source mais pura

### Contras
- Página instável - arquivos podem não estar acessíveis
- Mecanismo ball-joint ≠ single-axis - exige redesign completo
- Documentado pelo próprio autor como "estágio infância"
- Menor validação estrutural
- Score mais baixo nos critérios do projeto

---

## Comparativo final

| Critério | A - Make3D #293133 | D - #1032352 | B - Appropedia |
|---|---|---|---|
| Score técnico | **4,2** | 3,65 | 2,85 |
| Custo estimado | R$ 43-64 | R$ 48-69 | R$ 30-40 |
| Material estrutura | PETG | PETG | PETG/PLA |
| Material batentes | TPU (trocar Filaflex) | TPU nativo | Impresso rígido |
| Articulação | Single-axis direto | Próximo - confirmar | Ball-joint (redesign) |
| CAD editável | ✅ Fusion 360 / STEP | ⚠ confirmar | ⚠ formato incerto |
| Testado | Não (pelo autor) | Sim | Não |
| Página acessível | ✅ | ✅ | ⚠ instável |
| Trabalho de remix | Baixo | Médio | Alto |

---

## Como votar

Responder com:
- **Voto:** A / D / B / A+D (combinar elementos dos dois)
- **Razão:** 1-2 linhas

> Recomendação técnica: **A como base principal** (score 4,2, single-axis direto, CAD editável)
> com elementos de D se o CAD for editável (material nativo PETG+TPU sem troca).

---

## ✅ RESULTADO DA VOTAÇÃO (08/06/2026)

**Voto do grupo: A — Make3D / Printables #293133.** Base travada; download e dimensionamento concluídos. Detalhes e ressalvas (sem STEP no pacote; escala ao pé 26–27 cm) em `decisao_design_base.md`.

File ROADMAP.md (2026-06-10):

# Roadmap - Prótese Funcional Pé-Tornozelo 3D
**Dispositivos de Reabilitação - FUMEC - Entrega: 22/06/2026**

> Produto físico + Relatório técnico + Apresentação formal
> Caminho crítico: **Decisão de design -> CAD -> Envio para impressão externa**
> ⚠ Impressão terceirizada: STLs saem até **13/06** - prazo antecipado em 1 dia vs. plano original.

---

## Cronograma geral

```mermaid
gantt
    title Prótese Pé-Tornozelo 3D - 06 a 22/06
    dateFormat  YYYY-MM-DD
    axisFormat  %d/%m

    section Design
    Decisão design-base          :crit, d1, 2026-06-06, 1d
    Download STL / CAD           :d2, after d1, 1d

    section Engenharia
    Dimensionamento (script)     :e1, 2026-06-07, 2d
    Material e parâmetros finais :e2, after e1, 1d

    section CAD
    Importar e adaptar base      :crit, c1, 2026-06-09, 2d
    Articulação single-axis      :crit, c2, after c1, 2d
    Travar design + exportar STL :milestone, crit, 2026-06-13, 0d

    section Fabricação
    Envio para impressão externa :crit, p0, 2026-06-13, 1d
    Impressão (terceirizado)     :p1, 2026-06-13, 3d
    Retirada das peças           :p2, after p1, 1d
    Montagem                     :m1, 2026-06-19, 1d

    section Validação
    Teste de ADM e carga         :v1, 2026-06-20, 1d
    Registro fotos/vídeo         :v2, 2026-06-20, 1d

    section Entrega
    Relatório técnico completo   :r1, 2026-06-21, 1d
    Slides + ensaio              :r2, 2026-06-21, 1d
    Apresentação formal          :milestone, crit, 2026-06-22, 0d
```

---

## Árvore de tarefas por fase

```
╔══════════════════════════════════════════════════════════════════╗
║  FASE 1 · DECISÃO DE DESIGN                  ✅ CONCLUÍDA 08/06  ║
╚══════════════════════════════════════════════════════════════════╝
  │
  ├─ [x] Leitura da matriz de decisão (refs/decisao_design_base.md)
  ├─ [x] ◆ Seleção do design-base: A — Make3D #293133 (voto do grupo, 08/06)
  └─ [x] Download dos STLs -> cad/A_make3d_293133/ (sem STEP - só malha)

╔══════════════════════════════════════════════════════════════════╗
║  FASE 2 · ENGENHARIA                         ✅ CONCLUÍDA 09/06  ║
╚══════════════════════════════════════════════════════════════════╝
  │  (MINERVA Missão 1 + Missão 1.5)
  │
  ├─ [x] Medição de B, H, L do keel no STL (parse numpy direto)
  │         └─ seção crítica medida: B=43 H=37 L=55 mm (InnerFoot.stl)
  ├─ [x] Execução de testes/dimensionamento.py com dimensões reais
  │         ├─ PETG: t_parede ≥ 4,3 mm · FS 2,5 · σ_adm 9 MPa ✔
  │         ├─ PLA-CF descartado (t=10 mm, anisotropia Z agravada)
  │         └─ Elo fraco = furo no plástico (bearing) → bucha metálica obrigatória
  ├─ [x] ◆ Material confirmado: PETG (keel) · TPU 95A (batentes) · M8 8.8 (eixo)
  └─ [x] Levantamento da articulação (MINERVA 1.5 — cad/A_make3d_293133/MEDIDAS_ARTICULACAO.md)
           ├─ furo nativo do pino: Ø4,8 mm (≈M5) → re-furar Ø8,4 no CAD
           ├─ bore TopJoint: Ø10,0 mm → casa exatamente com bucha nylon 10×8 (OD10/ID8)
           ├─ batente RubberCube: envelope 22,85 × 19,04 × 28 mm → reproduzir em TPU 95A
           ├─ Insert (pylon): interface custom retangular, NÃO é pirâmide ISO 30 mm
           ├─ escala: pé nativo 210 mm → alvo 265 mm = fator ×1,262
           └─ sem STEP/F3D oficial — remix via edição de malha (Blender)

╔══════════════════════════════════════════════════════════════════╗
║  FASE 3 · CAD (BLENDER)                              09-13/06    ║
╚══════════════════════════════════════════════════════════════════╝
  │  ⚠ GARGALO — prazo real 13/06 (envio externo no mesmo dia)
  │  Ferramenta: Blender (edição de malha). Referência completa:
  │  cad/A_make3d_293133/MEDIDAS_ARTICULACAO.md
  │
  ├─ [ ] ⚠ ANTES de abrir o Blender — comprar ferragem (urgente):
  │         ├─ bucha nylon 10×8 (OD 10 / ID 8) — 2 un.
  │         ├─ parafuso M8 × 60 mm classe 8.8 — 1 un.
  │         └─ porca M8 + 2× arruela M8
  │
  ├─ [x] ◆ Decisão pylon: **Opção A — manter Insert custom do design-base** (grupo, 09/06)
  │         → conector simplificado integrado ao modelo; suficiente para demonstração acadêmica
  │
  ├─ [ ] Blender — importar os 5 STLs de cad/A_make3d_293133/:
  │         InnerFoot · TopJoint · FootRubber · RubberCube · Insert
  │
  ├─ [ ] Escalar o CASCO ×1,262 (não escalar a junta junto):
  │         ├─ selecionar: FootRubber + InnerFoot (+ Insert se mantiver custom)
  │         ├─ S → 1.262 → Enter (escala uniforme global)
  │         └─ NÃO incluir TopJoint na seleção — bore Ø10 nativo deve ser mantido
  │
  ├─ [ ] Re-furar InnerFoot (M5 nativo → M8):
  │         ├─ Add → Cylinder: Ø 8,4 mm, eixo Y, centro em X ≈ −6,2 (escale o X tbm)
  │         ├─ Boolean Difference: InnerFoot − cilindro
  │         └─ resultado: furo Ø8,4 coaxial ao bore Ø10 do TopJoint
  │
  ├─ [ ] TopJoint — ajustar encaixe ao casco escalado:
  │         ├─ bore Ø10 intacto (assento da bucha nylon 10×8 — não alterar)
  │         └─ encaixe lateral/inferior ao InnerFoot escalado: ajustar malha se necessário
  │
  ├─ [ ] Batentes dorsal e plantar (2 peças separadas em TPU 95A):
  │         ├─ envelope base: 22,85 × 19,04 × 28 mm (RubberCube original)
  │         ├─ posicionar anterior (batente dorsal, limita dorsiflexão 10-15°)
  │         ├─ posicionar posterior (batente plantar, limita plantarflexão 15-20°)
  │         └─ exportar como STLs separados (material diferente no slicer)
  │
  ├─ [ ] ⚡ MINI-IMPRESSÃO LOCAL — validar a junta antes de enviar tudo:
  │         ├─ exportar só InnerFoot + TopJoint editados
  │         ├─ imprimir em PETG (parâmetros normais, não precisa de FS aqui)
  │         ├─ montar com M8 + bucha 10×8 + anilhas e testar:
  │         │    □ o M8 passa limpo pelo Ø8,4?
  │         │    □ a bucha 10×8 assenta no bore Ø10 sem folga excessiva?
  │         │    □ a junta gira livre, sem travar?
  │         └─ se não: ajustar Ø (FDM real ≠ nominal; esperar +0,1–0,2 mm de folga)
  │
  ├─ [ ] Ajuste de tolerâncias pós mini-impressão
  │
  ├─ [ ] ◆ TRAVAR DESIGN — 13/06 (não alterar depois do envio)
  │
  └─ [ ] Exportar STLs finais por peça, nomeados:
           keel_petg.stl · tornozelo_superior_petg.stl · batente_dorsal_tpu.stl
           batente_plantar_tpu.stl · sola_petg.stl · conector_pylon_petg.stl
           + criar slicing/ESPECIFICACOES_IMPRESSAO.md

╔══════════════════════════════════════════════════════════════════╗
║  FASE 4 · ENVIO PARA IMPRESSÃO EXTERNA               13/06       ║
╚══════════════════════════════════════════════════════════════════╝
  │  ⚠ Sem slicer necessário - entregar STL + especificações
  │
  ├─ [ ] Conferir todos os STLs (um por peça, sem erros de malha)
  ├─ [ ] Enviar STLs + slicing/ESPECIFICACOES_IMPRESSAO.md
  ├─ [ ] Confirmar prazo de entrega e retirada
  └─ [ ] Reservar opção de impressora local para emergência

╔══════════════════════════════════════════════════════════════════╗
║  FASE 5 · RETIRADA + INSPEÇÃO                        16-17/06    ║
╚══════════════════════════════════════════════════════════════════╝
  │
  ├─ [ ] Inspeção visual + dimensional de cada peça
  ├─ [ ] Registro fotográfico das peças -> fotos/
  └─ [ ] Solicitar reimpressão se necessário (buffer até 18/06)

╔══════════════════════════════════════════════════════════════════╗
║  FASE 6 · MONTAGEM                                   19/06       ║
╚══════════════════════════════════════════════════════════════════╝
  │
  ├─ [ ] Montagem da articulação (eixo M8 + porca + bucha + batentes)
  ├─ [ ] Encaixe keel + pylon + pé
  ├─ [ ] Verificação de movimento livre e batentes
  └─ [ ] Registro fotográfico da montagem -> fotos/

╔══════════════════════════════════════════════════════════════════╗
║  FASE 7 · VALIDAÇÃO                                  20/06       ║
╚══════════════════════════════════════════════════════════════════╝
  │
  ├─ [ ] Teste de ADM
  │         ├─ medir dorsiflexão real (alvo: 10-15°)
  │         └─ medir plantarflexão real (alvo: 15-20°)
  ├─ [ ] Teste de carga
  │         ├─ aplicar carga conhecida (estático)
  │         └─ observar e registrar deformação / ausência de falha
  ├─ [ ] Planilha de custo real -> testes/custo.csv
  └─ [ ] Registro em vídeo do ciclo de movimento -> fotos/

╔══════════════════════════════════════════════════════════════════╗
║  FASE 8 · RELATÓRIO + SLIDES                         21/06       ║
╚══════════════════════════════════════════════════════════════════╝
  │
  ├─ [ ] Relatório técnico (RELATORIO.md)
  │         ├─ seções 2, 3, 5 - já preenchidas pela Missão 1
  │         ├─ seção 4 - concepção/CAD (redigir pelo grupo)
  │         ├─ seções 6, 7, 8, 9 - análise dos dados de validação
  │         └─ abstract + referências ABNT
  ├─ [ ] Slides da apresentação
  │         ├─ problema + motivação
  │         ├─ biomecânica e requisitos
  │         ├─ design + decisões
  │         ├─ fabricação + parâmetros
  │         └─ validação + resultados + conclusão
  └─ [ ] Ensaio cronometrado da apresentação

╔══════════════════════════════════════════════════════════════════╗
║  MARCO FINAL · APRESENTAÇÃO FORMAL                   22/06       ║
╚══════════════════════════════════════════════════════════════════╝
  │
  ├─ Produto físico funcional em mãos
  ├─ Relatório técnico entregue
  └─ Defesa dos trade-offs de engenharia
```

---

## Dependências críticas

```
Decisão design-base (06/06)
       │
       ▼
  Download CAD ──────────────── Dimensionamento.py (paralelo)
       │                                │
       ▼                                ▼
  CAD completo ◄──────────── Material + parâmetros confirmados
       │
       ▼
  ◆ TRAVAR + EXPORTAR STLs (13/06) ◄─ prazo real antecipado
       │
       ▼
  Envio impressão externa ──► Retirada ──► Montagem ──► Validação
                                                │
                                      ┌─────────┴──────────┐
                                      ▼                    ▼
                                Relatório               Slides
                                      └─────────┬──────────┘
                                                ▼
                                        APRESENTAÇÃO 22/06
```

---

## Status atual

| Fase | Status | Observação |
|---|---|---|
| Fundação técnica (biomecânica, requisitos, dimensionamento) | ✅ | MINERVA Missão 1 |
| Levantamento da articulação + escala | ✅ | MINERVA Missão 1.5 — ver `cad/A_make3d_293133/MEDIDAS_ARTICULACAO.md` |
| Decisão design-base | ✅ | **A — Make3D #293133** (voto do grupo, 08/06) |
| Download CAD | ✅ | STLs em `cad/A_make3d_293133/`; dimensionamento re-rodado com geometria medida |
| **CAD / edição de malha** | ✅ | Feito via script (`cad/A_make3d_293133/processar_pecas.py`) em vez do Blender: escala ×1,262 + furo M8. STLs finais em `stl/` |
| Mini-impressão da junta (teste encaixe M8) | ⏳ **PRÓXIMO** | Imprimir keel + tornozelo, testar M8 + bucha antes de enviar tudo |
| Envio impressão externa | ⏳ Pendente | STLs prontos + `slicing/ESPECIFICACOES_IMPRESSAO.md`. Confirmar fornecedor até 13/06 |
| Retirada + inspeção | ⏳ Pendente | 16–17/06 (estimativa) |
| Montagem | ⏳ Pendente | 19/06 |
| Validação (ADM + carga + fotos) | ⏳ Pendente | 20/06 → dispara MINERVA Missão 2 |
| Relatório técnico completo | ⏳ Pendente | MINERVA Missão 2 (pós-validação) + seção 4 (pós-CAD) |
| Slides + ensaio | ⏳ Pendente | 21/06 |
| **APRESENTAÇÃO FORMAL** | ⏳ | **22/06** |

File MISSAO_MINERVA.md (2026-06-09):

# Missões para a MINERVA — Prótese pé-tornozelo

> A MINERVA abre limpa (sem memória). Cada missão é autossuficiente: ela lê os arquivos
> do projeto antes de agir. Régua do modo: tudo defensável numa sabatina. João é dono das
> decisões difíceis; a MINERVA fundamenta, calcula, escreve e versiona.

---

## MISSÃO 1 — Fundação técnica (rodar AGORA, em paralelo ao CAD do João)

**Contexto obrigatório (leia antes de tudo):**
- `~/biomed-lab/protese-tornozelo/README.md` (decisões, requisitos, régua, candidatos, riscos)
- `~/biomed-lab/protese-tornozelo/RELATORIO.md` (esqueleto a preencher)
- `~/biomed-lab/protese-tornozelo/PLANO.md` (cronograma)
- `~/biomed-lab/protese-tornozelo/refs/FONTES.md` (links dos designs e papers)

**Decisões já travadas (não reabrir):** remix open-source, articulação single-axis, alvo
adulto padrão (~70 kg, pé 26–27 cm), carga de projeto 1,5×BW ≈ 1030 N, fator de segurança 2–3.

**Entregáveis (ponta a ponta, e commitar+push ao final):**

1. **Requisitos de engenharia finalizados** — fechar a tabela de requisitos com valores
   justificados (cada número com 1 linha de razão). Atualiza a seção 3 do `RELATORIO.md`.

2. **Fundamentação biomecânica** — ciclo da marcha e papel do tornozelo, ADM fisiológica
   (dorsi ~10°, plantar ~20°), cargas de pico no heel-strike. Com fontes citadas (use as de
   `refs/FONTES.md` + busque o que faltar). Vira a seção 2 do `RELATORIO.md`.

3. **Matriz de decisão dos 3 design-base** (Make3D/Printables, Appropedia, Colorado Mines) —
   critérios: imprimibilidade FDM, robustez estrutural, facilidade de remix/edição, aderência
   ao single-axis, licença. Pontue, recomende **qual remixar** e liste o que aproveitar e o que
   mudar. **NÃO decida sozinha o veredito final** — entregue a recomendação fundamentada para
   o João bater o martelo. Salva em `refs/decisao_design_base.md`.

4. **Dimensionamento estrutural preliminar** — script Python reproduzível em
   `testes/dimensionamento.py` que:
   - calcula a tensão na seção crítica do keel sob 1030 N com FS 2–3;
   - aplica derating de resistência do FDM no eixo Z (adesão entre camadas ~50% da resistência
     no plano) — esse ponto é central, deixe explícito;
   - compara **PETG vs PLA-CF** e recomenda o material;
   - recomenda espessura de parede, nº de paredes e infill mínimos justificados;
   - dimensiona o eixo M8 da articulação ao cisalhamento;
   - gera gráfico(s) (ex: tensão vs espessura de parede).
   Resultados + justificativa preenchem a seção 5 do `RELATORIO.md`.

**Restrições:**
- Não inventar dados. Cite fonte de cada número de material/biomecânica.
- O dimensionamento é **preliminar/paramétrico** — marque claramente o que precisa ser
  refinado com as dimensões reais do STL depois que o design-base for escolhido e baixado.
- Explique cada decisão-chave em 1–2 linhas (régua da sabatina).
- Ao final: `git add` + `commit` + `push` no repo `biomed-lab`.

**Prompt de disparo (colar na MINERVA):**
> Leia `~/biomed-lab/protese-tornozelo/MISSAO_MINERVA.md` e execute a Missão 1 inteira,
> ponta a ponta, commitando ao final.

---

## MISSÃO 1.5 — Levantamento da articulação + escala (rodar AGORA, antes do CAD)

**Contexto:** design-base TRAVADO = **A, Make3D / Printables #293133**. STLs já no repo em
`cad/A_make3d_293133/` (InnerFoot = keel; TopJoint = junta superior; RubberCube = batente;
Insert; FootRubber = sola). Dimensionamento já re-rodado com geometria medida (B=43, H=37,
L=55 → PETG t≈4,3 mm). Esta missão NÃO é o CAD (isso é do João) — é a medição que alimenta o CAD.

**Entregáveis (medir na malha, não chutar; commitar+push ao final):**

1. **Geometria da articulação single-axis** — medir nos STLs e documentar em
   `cad/A_make3d_293133/MEDIDAS_ARTICULACAO.md`:
   - localização e diâmetro do furo/eixo nativo na junta (TopJoint × InnerFoot) — confirmar se já é ~M8 ou precisa rebaixar/abrir;
   - dimensões do bolso/encaixe do batente (RubberCube) — base p/ trocar por TPU 95A;
   - interface do conector de pylon (Insert) — diâmetro/altura, comparar com pirâmide 30 mm padrão;
   - distância entre faces da junta (folga p/ bucha nylon no furo).
   Usar parse direto da malha binária (numpy) ou trimesh; **não inventar cota**.

2. **Análise de escala ×1,26 (pé ~21 → 26–27 cm)** — tabela peça-por-peça do que muda
   ao escalar: comprimento do pé, seção do keel, diâmetro do furo (⚠ escalar a malha
   escala o furo p/ ~10 mm → decidir se mantém M8 e re-fura, ou usa M10), bolso do batente,
   massa/filamento estimados. Recomendar: escalar a malha inteira OU escalar só o casco e
   manter ferragem M8. Salvar em `cad/A_make3d_293133/MEDIDAS_ARTICULACAO.md` (mesma nota).

3. **Caça ao CAD editável** — verificar se o F3D/STEP de #293133 existe no Printables
   (o ZIP baixado só trouxe STL). Se sim, anotar link/instrução em `refs/FONTES.md`; se não,
   registrar que o remix será por edição de malha (Blender) e qual o caminho mínimo.

**Restrições:** cada cota com origem (qual STL, como medida). Marcar o que for estimativa.
Régua da sabatina: defensável. Ao final: `git add` + `commit` + `push` no `biomed-lab`.

**Prompt de disparo (colar na MINERVA):**
> Leia `~/biomed-lab/protese-tornozelo/MISSAO_MINERVA.md` e execute a Missão 1.5 inteira,
> ponta a ponta, commitando ao final.

---

## MISSÃO 2 — Análise dos dados de validação (depois dos testes físicos)
*(a detalhar quando houver dados de ADM e carga)*

## MISSÃO 3 — Relatório técnico completo (fase final)
*(a detalhar quando o produto estiver validado)*

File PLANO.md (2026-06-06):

# Plano - 16 dias até 22/06

> Caminho crítico: **escolher base -> CAD -> envio para impressão externa**.
> Impressão terceirizada: STLs precisam sair até **13/06** (prazo de entrega 1-3 dias).
> Travar o design antes do estágio começar (15/06) - mas o envio é antes disso.

| Data | Entrega | Dep. | Risco |
|---|---|---|---|
| **06/06** | Decisão do design-base (ler matriz + bater martelo) + registrar no README | - | ⛔ trava tudo |
| **07/06** | Download STL + STEP/F3D do design escolhido para `cad/` e `refs/` | 06 | baixo |
| **09/06** | Medir B, H, L do keel no STL; rodar `dimensionamento.py` com valores reais; confirmar material | 07 | médio |
| **13/06** | **CAD completo - TRAVAR e exportar STLs** por peça nomeados + doc de especificações de impressão | 09 | ⛔ crítico - envio no mesmo dia |
| **13/06** | **Enviar para impressão externa** com especificações (material, infill, orientação, qtd) | 13 | alto - logística |
| **15/06** | ⚠ Início do estágio (08-14h) | - | colisão de agenda |
| **16–17/06** | Retirada das peças impressas (estimativa - confirmar com quem imprimir) | 13 | médio |
| **18/06** | **Buffer**: reimpressão de emergência se necessário (ter opção de impressora local reserva) | 16 | alto |
| **19/06** | Montagem da articulação (eixo M8 + bucha + batentes TPU) | 16 | médio |
| **20/06** | Validação funcional: ADM + carga + fotos/vídeo | 19 | médio |
| **21/06** | Relatório técnico fechado + slides + ensaio | 20 | alto (acúmulo) |
| **22/06** | **APRESENTAÇÃO** | 21 | - |

### Especificações a entregar para quem imprimir

Arquivo `slicing/ESPECIFICACOES_IMPRESSAO.md` a criar junto com os STLs:

| Peça | Material | Infill | Paredes | Orientação | Qtd |
|---|---|---|---|---|---|
| keel (estrutura principal) | PETG | ≥ 40% | ≥ 3 | deitado (carga no plano XY) | 1 |
| carcaça do tornozelo | PETG | ≥ 40% | ≥ 3 | a definir no CAD | 1 |
| batente dorsal | TPU 95A | 30-40% | 3 | a definir | 1 |
| batente plantar | TPU 95A | 30-40% | 3 | a definir | 1 |
| conector de pylon | PETG | ≥ 50% | ≥ 4 | a definir | 1 |

> Peças e quantidades a confirmar após CAD finalizado.

### Regras do plano
- **CAD trava em 13/06, não 14/06** - envio externo não espera.
- **Ter opção de impressora local reserva** para emergência pós-retirada (peça com defeito).
- Relatório alimentar em paralelo ao CAD - não deixar tudo pra 21/06.
- Colisões de agenda: estágio 15/06 (08-14h) + prova Informática Médica / Eng. Clínica 25/06.

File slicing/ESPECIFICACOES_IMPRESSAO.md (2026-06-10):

# Especificações de impressão — prótese pé-tornozelo

> Acompanha os STLs em `../stl/`. Design-base A (Make3D #293133), remixado.
> Peças escaladas ×1,262 (pé ~26-27 cm), exceto o tornozelo superior (nativo).

## Tabela por peça

| STL | Material | Qtd | Infill | Paredes | Orientação | Observação |
|---|---|---|---|---|---|---|
| `keel_petg.stl` | PETG | 1 | **50%** | **≥4** | **deitado** (eixo longo na horizontal) | Peça estrutural principal. Furo M8 já modelado. |
| `tornozelo_superior_petg.stl` | PETG | 1 | 50% | ≥4 | a favor da resistência do bore | Bore Ø10 = assento da bucha nylon 10×8. |
| `conector_pylon_petg.stl` | PETG | 1 | 50% | ≥4 | a definir | Interface com o pylon. |
| `sola_tpu.stl` | TPU 95A | 1 | 35% | 3 | base plana na mesa | **265 mm** no eixo maior — exige mesa grande. |
| `batente_tpu.stl` | TPU 95A | **2** | 35% | 3 | qualquer | Batentes dorsi/plantar (definem a ADM). |

## Parâmetros gerais
- **Layer height:** 0,2 mm
- **PETG:** bico 230-240 °C, mesa 70-80 °C
- **TPU 95A:** velocidade reduzida (flexível), retração baixa

## Pontos críticos
1. **Keel deitado** — a carga de flexão solicita o plano XY (forte); imprimir em pé colocaria a carga na adesão entre camadas (eixo Z, 30-50% mais fraco).
2. **Sola = 265 mm** — não cabe em mesa padrão 220 mm. Confirmar impressora ≥ 270 mm OU fatiar em 2 partes.
3. **Bore do tornozelo** intacto em Ø10 — não redimensionar; é o assento da bucha.

## Estimativa de filamento
- PETG: ~215 g
- TPU 95A: ~400 g

## Ferragem de montagem (comprar à parte)
- 1× parafuso M8 × 60 mm (eixo da articulação)
- 2× bucha nylon 10×8 (OD 10 / ID 8) — mancal no bore do tornozelo
- 1× porca M8 (autotravante de preferência) + 2-4× arruela M8

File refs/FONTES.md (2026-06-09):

# Fontes e referências

## Designs open-source (candidatos a remix)
- [A] Make3D - Prosthetic Foot Prototype ✅ **TRAVADO**: https://www.printables.com/model/293133-prosthetic-foot-prototype
  - Autor: Make3D Company Ltd. Descrição cita **Fusion 360**, mas **só publica malha (STL)** —
    o `.f3d`/STEP nativo **NÃO está disponível** (verificado em 2026-06-09). → remix por
    **edição de malha (Blender)**: escalar ×1,262 + Boolean p/ furo M8. Detalhe em
    `cad/A_make3d_293133/MEDIDAS_ARTICULACAO.md` (Missão 1.5).
- [D] Prosthetic Foot-Ankle for 3D Printing ✅ Principal: https://www.printables.com/model/1032352-prosthetic_foot-ankle-for-3d-printing
- [B] Appropedia - 3D printed prosthetic foot ⚠ Plano B (página instável): https://www.appropedia.org/3D_printed_prosthetic_foot

## Referência acadêmica (fundamentação / FEA / materiais)
- Nature Scientific Reports — pé protético com rigidez não-linear do toe joint (FEA): https://www.nature.com/articles/s41598-021-98839-3
- Open-source 3D printing em próteses (review, MDPI Machines): https://www.mdpi.com/2075-1702/10/6/413
- ResearchGate — Low-cost 3D-printable prosthetic foot (composites PLA/CF): https://www.researchgate.net/publication/281255578_Low-cost_3D-printable_prosthetic_foot
- ResearchGate — Design and Analysis of 3D Printable Foot Prosthesis: https://www.researchgate.net/publication/318989655_Design_and_Analysis_of_3D_Printable_Foot_Prosthesis

> Dados úteis já extraídos: tensão máx. ~15 MPa no heel-strike a 150% do peso corporal;
> recurso de projeto = split forefoot/heel; SACH = baseline não-articulado para comparação.

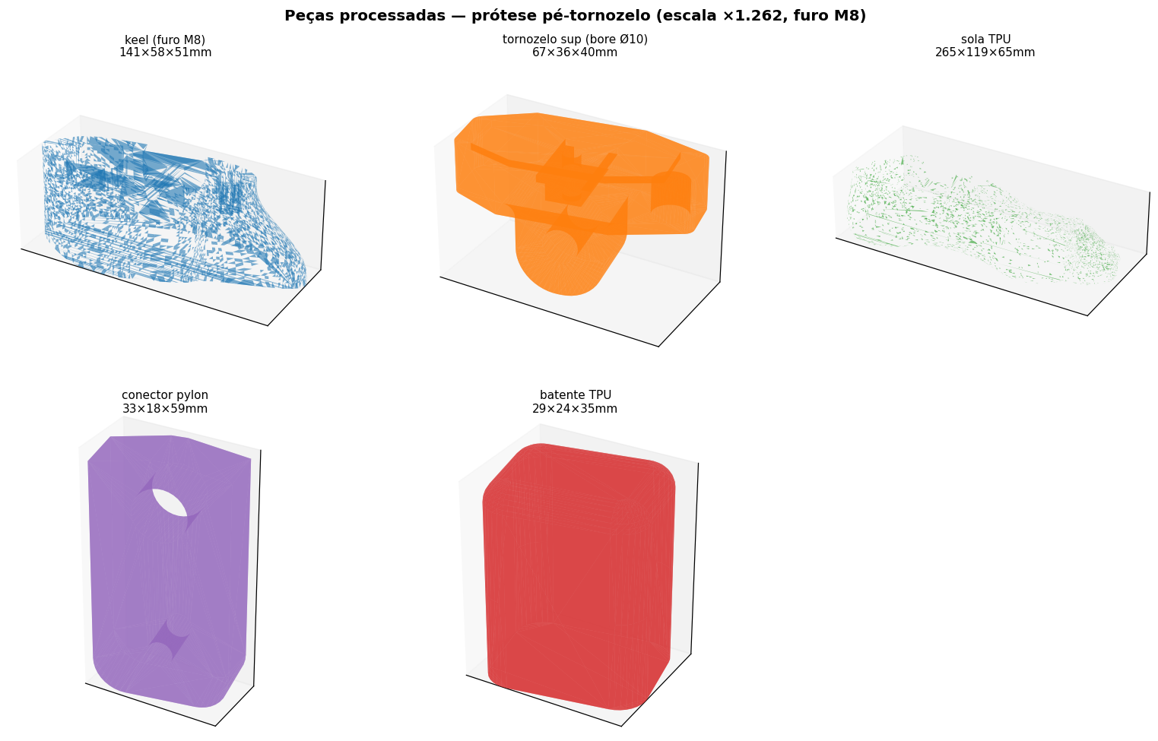
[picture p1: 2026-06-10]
stl/preview_pecas.png

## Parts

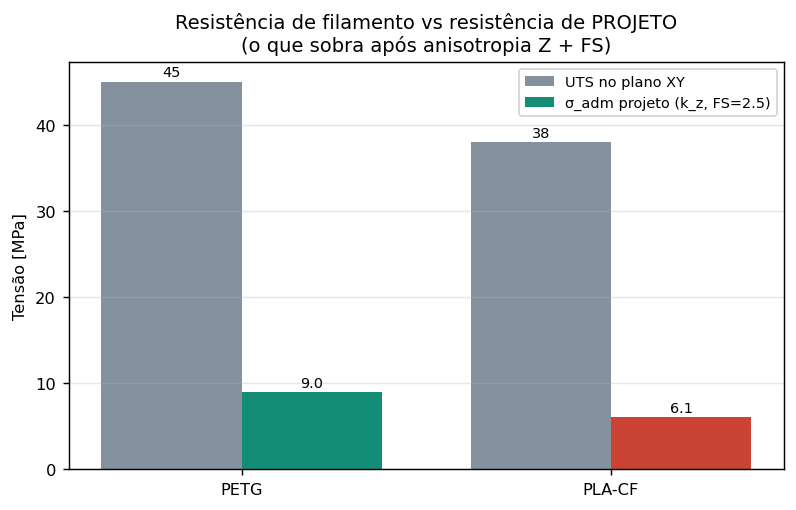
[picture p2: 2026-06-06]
testes/dimensionamento_materiais.png

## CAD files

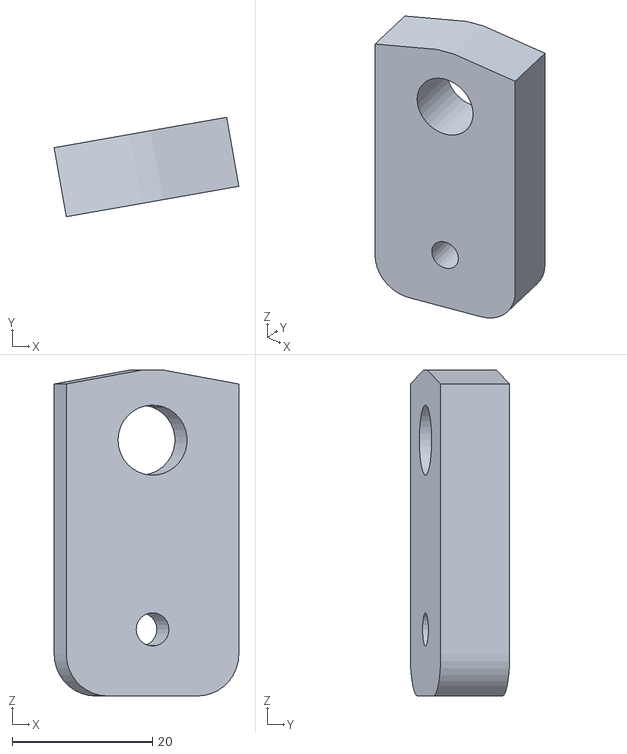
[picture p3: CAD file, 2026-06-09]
cad/A_make3d_293133/Insert.stl
26.4 x 14.2 x 46.5

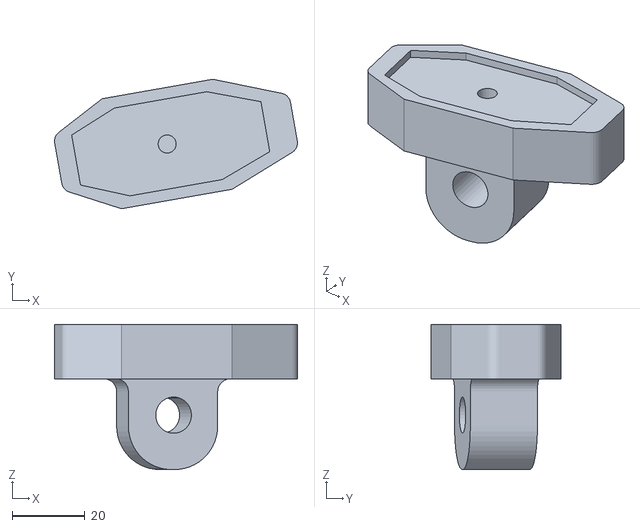
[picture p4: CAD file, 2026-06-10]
stl/tornozelo_superior_petg.stl
67.0 x 35.7 x 40.0

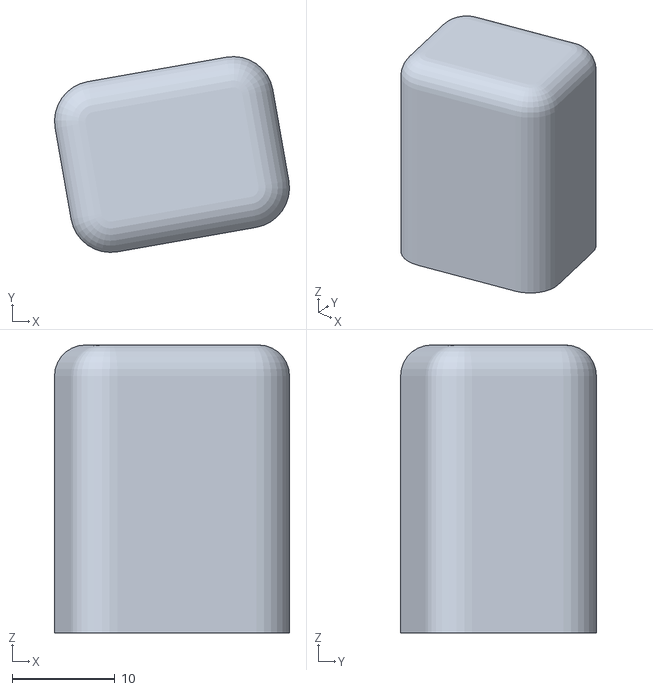
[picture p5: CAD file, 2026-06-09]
cad/A_make3d_293133/RubberCube.stl
22.8 x 19.0 x 28.0

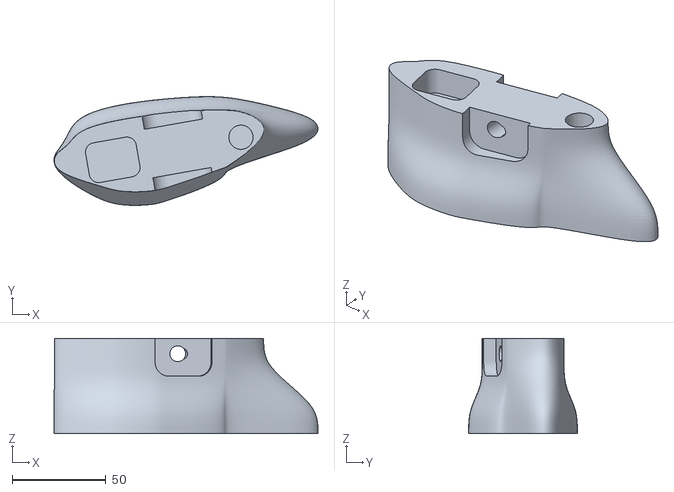
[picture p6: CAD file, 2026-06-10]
stl/keel_petg.stl
140.8 x 58.0 x 50.8

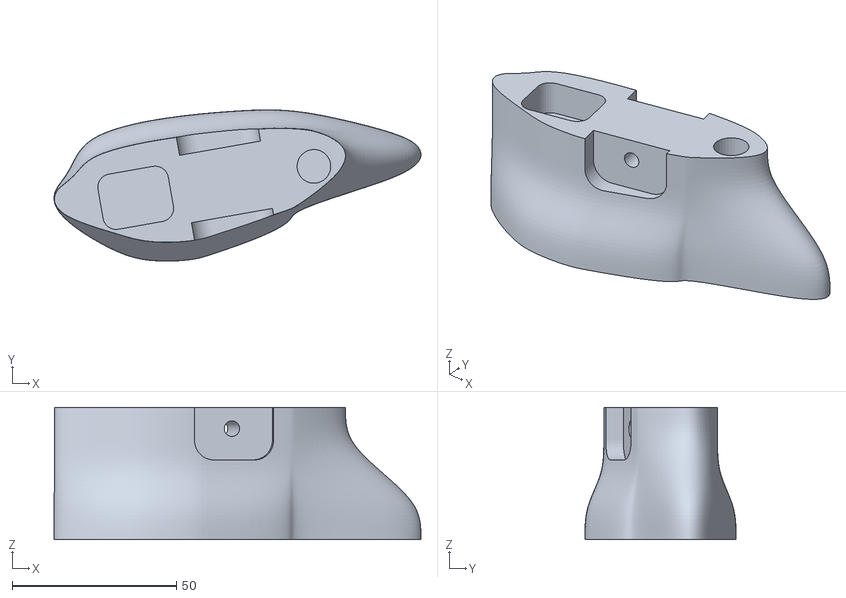
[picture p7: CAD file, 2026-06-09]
cad/A_make3d_293133/InnerFoot.stl
111.6 x 46.0 x 40.2

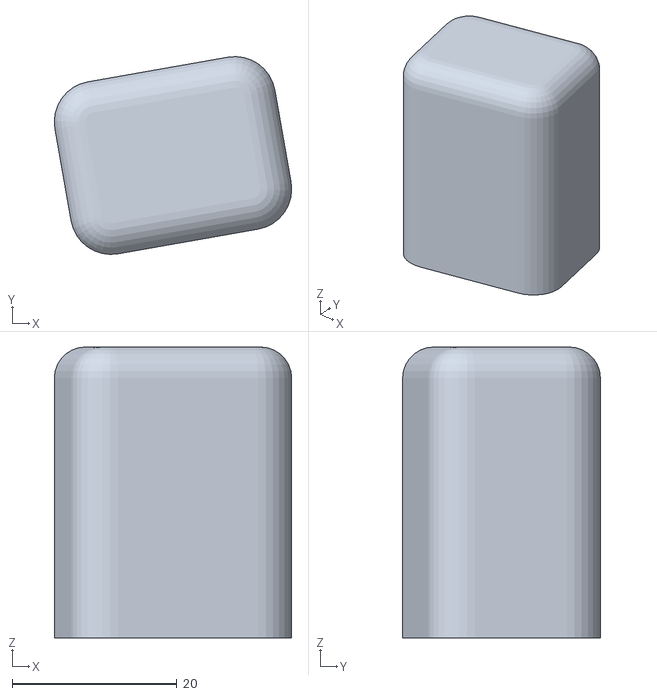
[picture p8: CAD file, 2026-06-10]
stl/batente_tpu.stl
28.8 x 24.0 x 35.3

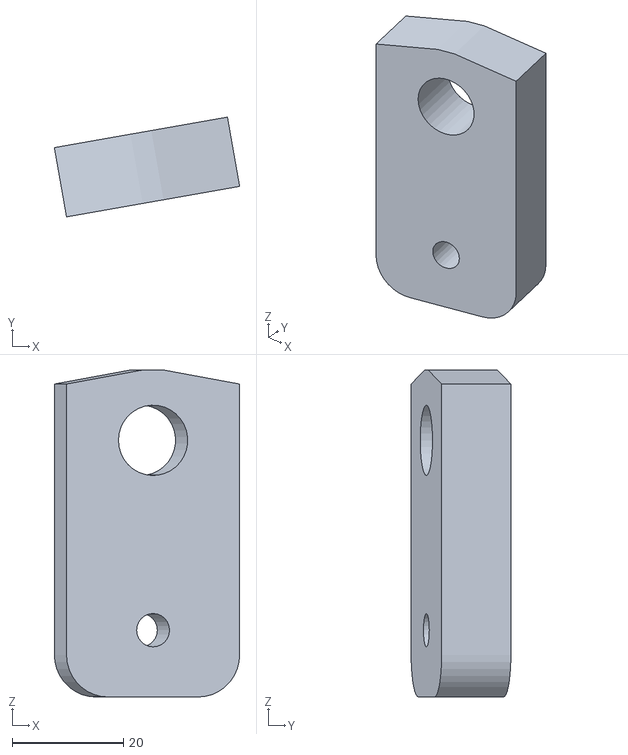
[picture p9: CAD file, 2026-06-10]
stl/conector_pylon_petg.stl
33.3 x 17.9 x 58.7

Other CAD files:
cad/A_make3d_293133/TopJoint.stl

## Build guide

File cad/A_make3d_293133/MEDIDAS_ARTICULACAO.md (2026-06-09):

# Levantamento da articulação + escala — design-base A (Make3D / Printables #293133)

> **Missão 1.5** — medição que alimenta o CAD do João (o CAD em si é dele).
> Tudo aqui foi **medido nos STLs nativos**, não chutado. Script reprodutível:
> [`medir_articulacao.py`](medir_articulacao.py) (trimesh + numpy). Figura:
> [`medidas_articulacao.png`](medidas_articulacao.png).
> Régua da sabatina: cada cota tem origem (qual STL, como foi medida).

## Como foi medido (defensável)

- As 5 peças (`InnerFoot`, `TopJoint`, `RubberCube`, `Insert`, `FootRubber`) estão num
  **mesmo referencial de montagem**, porém **explodidas em Z** (cada peça erguida no eixo
  vertical para visualização / mesa de impressão). Prova: o furo do pino e o bore do pino
  têm o **mesmo X** (ΔX = 0,18 mm) — eixo de pivô compartilhado; só o Z difere.
- **Eixos do STL:** `X` = ântero-posterior (calcanhar X<0, dedos X>0) · `Y` = médio-lateral
  = **eixo do pino** (dorsi/plantarflexão gira em torno de Y) · `Z` = vertical.
- **Furos/bores:** secção planar (`mesh.section`) perpendicular ao eixo do furo + ajuste de
  círculo por mínimos quadrados. Qualidade `res = σ_raio / raio_médio`; `res < 0,05` = círculo
  real. Diâmetros varridos em dezenas de secções e medianados.

---

## 1. Geometria da articulação single-axis

| Cota | Valor medido | Origem / como | `res` |
|---|---|---|---|
| **Furo do pino — InnerFoot (keel)** | **Ø 4,77 mm** | `InnerFoot.stl`, secção ⟂Y, mediana de 48 secções | 0,006 |
| Centro do furo (global) | X = −6,20 · Z = 63,50 mm | idem | — |
| Comprimento do furo (largura do knuckle) | 19,0 mm (Y 118,5→137,5) | extensão em Y onde o furo existe | — |
| Largura do bloco do tornozelo (InnerFoot) | 46,0 mm (em Y) | bbox da peça | — |
| **Bore do pino — TopJoint (junta superior)** | **Ø 10,06 mm** | `TopJoint.stl`, secção ⟂Y, mediana | 0,006 |
| Centro do bore (global) | X = −6,38 · Z = 90,50 mm | idem | — |
| Comprimento do bore | ~16 mm (Y 120→136) | extensão em Y do anel Ø10 | — |
| Parede mínima bore→exterior (TopJoint) | ≈ 5,0 mm | distância radial mín. ao contorno externo | — |
| **Coaxialidade do pivô** | **ΔX = 0,18 mm** | bore vs furo (mesmo eixo Y) | — |
| Offset de explosão (não é folga real) | ΔZ = 27,0 mm | peças erguidas em Z; montagem é coaxial | — |

### Veredito do pino — é ~M8? **NÃO.** Precisa normalizar.

O design nativo tem **dois diâmetros diferentes no mesmo eixo**: furo **Ø4,8** (≈ passagem
de **M5**) no InnerFoot e bore **Ø10,0** no TopJoint. Nenhum é M8. Para padronizar em **M8**
(coerente com o `testes/dimensionamento.py`, que dimensionou o eixo como M8 8.8):

1. **Abrir** o furo do InnerFoot de Ø4,8 → **Ø8,4** (folga de M8) e re-furar concêntrico.
2. **Aproveitar o bore Ø10 nativo do TopJoint** como assento de **bucha de nylon 10×8**
   (OD 10 / ID 8) — ela casa **exatamente** com o Ø10 medido. A bucha vira o mancal do M8
   e elimina folga plástico-contra-aço (bearing é o elo fraco da junta — ver
   [`../../testes/dimensionamento.py`](../../testes/dimensionamento.py)).
3. Parede de 5 mm ao redor do bore é suficiente para o assento da bucha sem fragilizar.

### Folga para bucha / anilha de nylon (faces da junta)

Bore (Ø10, 16 mm de comprimento) é mais largo que o furo (Ø4,8, knuckle de 19 mm): há
**degrau radial de ~2,6 mm/lado** e **~3 mm de folga axial** entre os comprimentos. Isso dá
espaço nativo para **anilhas/bucha de nylon (≈1–1,5 mm/lado)** entre as faces — reduz atrito
e desgaste do plástico na rotação. *(Cotas axiais a confirmar no CAD montado — as peças vêm
explodidas; ver caveat no fim.)*

---

## 2. Batente (RubberCube) e conector de pylon (Insert)

**RubberCube** — batente posterior (limita a plantarflexão; é a peça macia que define a ADM):
- Envelope **22,85 × 19,04 × 28,00 mm**, volume 9 610 mm³, preenchimento 0,79 da caixa
  (= **cunha sólida**, sem furos internos). *(`RubberCube.stl`, bbox + secções.)*
- **Trocar por TPU 95A com este mesmo envelope.** A dureza 95A é o que define a rigidez do
  batente e, com ela, a amplitude de movimento — é parâmetro de projeto, não cosmético.

**Insert** — conector proximal (interface com o pylon):
- Prisma externo **26,36 × 14,19 × 46,50 mm** (retangular, alto). *(`Insert.stl`, bbox.)*
- Cavidade interna ≈ **Ø11–12 mm**, mas **não é um bore cilíndrico contínuo** — são
  **dois recessos/soquetes** (em Z ≈ 62 mm e ≈ 94 mm), provavelmente para tubo + parafuso.
- **Não é a pirâmide ISO 30 mm** padrão de prótese: footprint 26×14 mm é retangular e menor
  que a base 30×30 de 4 furos. É **interface custom**. → decisão do João: manter o soquete
  simples (mais imprimível, suficiente para demonstração) ou adaptar a uma pirâmide 30 mm
  comercial (mais "real", porém depende de peça comprada).

---

## 3. Análise de escala ×1,26 (pé ~21 cm → 26–27 cm)

Pé nativo (`FootRubber.stl`, extensão em X) = **209,9 mm**. Alvo BR 40–41 = **265 mm** ⇒
**fator S = 1,262** (bate com o ×1,26 da missão).

**Regra geométrica** (escala uniforme da malha): comprimento ∝ S · seção ∝ S² · volume
(massa/filamento) ∝ S³. **Estrutural:** σ_flexão ∝ (P·L)/(B·H²) ∝ S/S³ = **1/S²** ⇒ escalar
**reduz** a tensão por **0,63×** — escala **ajuda** a estrutura (já antecipado no
`dimensionamento.py`; o caso nativo SCALE=1 é o pior caso de tensão).

| Peça / cota | Nativo | × S (1,262) | Observação |
|---|---:|---:|---|
| Comprimento do pé [mm] | 209,9 | 265,0 | alvo 26–27 cm ✔ |
| Furo pino InnerFoot Ø [mm] | 4,8 | **6,0** | ⚠ ainda ≠ M8 |
| Bore pino TopJoint Ø [mm] | 10,1 | **12,7** | ⚠ deixa de casar c/ bucha 10×8 |
| Recesso pylon Insert ≈Ø [mm] | 11,5 | 14,6 | interface cresce junto |
| Batente RubberCube vol [mm³] | 9 610 | 19 336 | filamento TPU **×2,01** |
| Keel InnerFoot vol [mm³] | 99 161 | 199 524 | filamento **×2,01** |
| Sola FootRubber vol [mm³] | 308 492 | 620 722 | filamento **×2,01** |

⚠ **Escalar a malha escala os furos.** O pino Ø4,8→Ø6,0 e o bore Ø10,1→Ø12,7 — **nenhum vira
M8**, e o bore escalado perde o casamento com a bucha de nylon 10×8 padrão. Ou seja: a
ferragem **tem de ser normalizada de qualquer modo**; escalar só piora o casamento com peça
de prateleira. E o filamento **~dobra** (×2,0).

### Recomendação (João bate o martelo)

**Escalar o casco e congelar a ferragem em M8** (em vez de escalar a malha inteira como bloco):

- **Escalar** uniformemente o **casco estrutural** (sola, keel, comprimento do pé) ×1,262 para
  chegar a 26–27 cm e ganhar o alívio estrutural de 0,63×.
- **NÃO escalar a interface da junta:** manter o assento do pino em **Ø10 nativo** (= bucha
  nylon 10×8) e abrir o furo do InnerFoot para **Ø8,4 (M8)**. Assim a **ferragem fica de
  prateleira** (parafuso M8 8.8 + bucha 10×8 + anilhas nylon), independente da escala.
- Motivo decisivo: o **Ø10 nativo já é a medida de uma bucha comercial** — escalar joga essa
  vantagem fora. Custo de manter a junta sem escala: revisar o encaixe local junta⇄casco no
  CAD para os dois casarem (edição local, não global).

*Alternativa (escalar tudo ×1,26):* mais simples no slicer e melhora a estrutura, mas obriga
bucha/eixo de medida não-padrão (Ø12,7 / re-furo Ø8,4 em furo Ø6,0). Defensável só se a
disponibilidade de ferragem custom não for problema.

---

## 4. Caça ao CAD editável (#293133)

- Página: <https://www.printables.com/model/293133-prosthetic-foot-prototype> — autor
  **Make3D Company Ltd**. A descrição diz que **“the design was made in Autodesk Fusion 360”**,
  mas **o `.f3d`/STEP nativo não está publicado para download** — os arquivos disponíveis são
  malha (o ZIP baixado trouxe só STL; a página lista arquivos no formato imprimível).
- **Conclusão:** não há CAD paramétrico oficial. O **remix será por edição de malha**.
  Caminho mínimo:
  1. **Blender** (grátis): importar STL → *Edit Mode* para o casco; **escalar ×1,262**
     (S/M/X·1.262) o conjunto do casco.
  2. Para o furo M8: *Boolean* com um cilindro Ø8,4 no eixo Y (centro X≈−6,2, Z do pivô) —
     re-furo concêntrico; e Boolean Ø10 mantido no TopJoint para a bucha.
  3. Batente: substituir o sólido do `RubberCube` por bloco TPU 95A do mesmo envelope.
  4. (Opcional) **Fusion 360 / FreeCAD**: *Mesh→BRep* só se for re-parametrizar de fato;
     para escalar + furar, o Blender resolve com menos atrito.
- Registrado também em [`../../refs/FONTES.md`](../../refs/FONTES.md).

---

## Caveats (refinar depois)

- Peças vêm **explodidas em Z** — folgas **axiais** da montagem (anilhas, encosto de faces)
  são estimadas pelos comprimentos; **confirmar no CAD montado** e na junta física.
- Cavidade do `Insert` é irregular (soquetes), não cilindro — Ø11–12 mm é aproximação do
  recesso, não um bore usinado.
- Dimensões viram definitivas **após** o casco escalado e o re-furo M8 no CAD do João; então
  re-rodar `medir_articulacao.py` na malha editada para validar as cotas finais.

> Reproduzir: `cd cad/A_make3d_293133 && python3 medir_articulacao.py`
> (requer `trimesh numpy scipy networkx shapely matplotlib`).

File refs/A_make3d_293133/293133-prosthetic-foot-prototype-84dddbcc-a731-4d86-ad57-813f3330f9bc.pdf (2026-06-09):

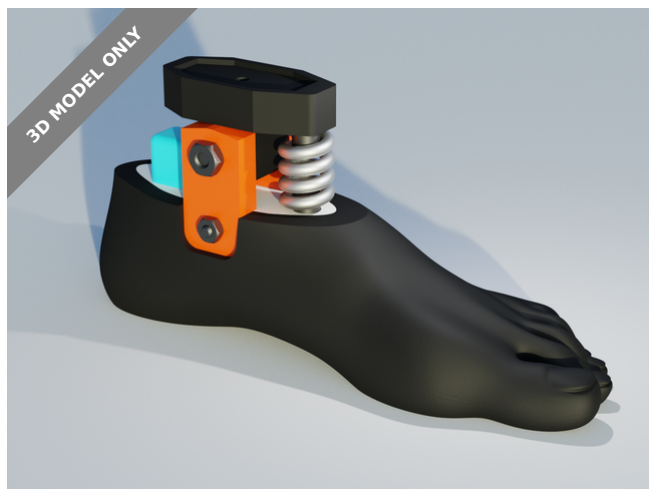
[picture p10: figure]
3D MODEL ONLY

# Summary

This is our new prosthetic foot prototype. It has not been properly tested

yet.

Healthcare (https://printables.com/model?categoryId=87) | > | Medical Tools (https://printables.com/model?categoryId=99)
Tags: printableprosthetics | prosthetic

This is a new 3D printable prosthetic foot with the connector to pylon used

on conventional prosthetics. It has the ankle joint and flexible fingers to

achieve better walking dynamics.

The design was made in Autodesk Fusion 360 and was printed in several

iterations before we have achieved the right fit, function and strength.

This design has not been tested properly yet. Use on your own risk.

### Print Settings:

### TopJoint, Inserts,InnerFoot

Perimeters: 5, Infill: 100%, Layer height: 0.25mm

Make3D Company Limited (https://printables.com/social/87427/about)

# Prosthetic Foot Prototype

VIEW IN BROWSER (https://printables.com/model/293133-prosthetic-foot-prototype)

updated 28. 11. 2022 | published 28. 11. 2022

•

# Model files

### RubberCube:

Filament: Filaflex40, Infill: 20-40% (depending on the weight of the

person and required rigidity), Layer height: 0.25mm

### FootRubber:

Filament: Filaflex40, Infill: 20-40% (depending on the weight of the

person and required rigidity), Layer height: 0.25mm

### Additional material:

3 bolts, nuts and washers for attaching the joint to the foot

1 metal cylinder diameter 10mm, length 20mm

Strong spring - depending on the weight of the person, sometimes we

use two springs inside each other or a 3D printed rubber block for higher rigidity.

### ASSEMBLING:

Glue the side joints on the top foot, and use size 10 bolt and nut to

tighten them

Insert the Flex Cube in the top foot

Insert the inside foot in the rubber foot. Use glue to attach the parts

together firmly. It might be very tricky to insert the parts together.

When using the tools pay attention not to damage the parts or hurt

yourself.

Pour glue in the hole found on the top part part of the foot and Insert

a metal cylinder (stainless steel is preferred) in the hole.

Insert the spring between the foot and top joint in between the pins

and add washers between the spring and 3D printed parts (we

recommend to glue the washers).

Insert the joint on the foot.

Attach a washer between and after the side joints , and insert the

bolt.

Tighten a bolt and nut slightly. Do not over tighten the nut.

Attach the conventional pylon joint on the top and tighten it with the

bolt. Dont forget to insert nut and washer on the side of the top part.

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
insert.stl

# License

This work is licensed under a

Creative Commons (4.0 International License)

Attribution-NonCommercial (http://creativecommons.org/licenses/by-nc/4.0/)

✖ | Sharing without ATTRIBUTION
✔ | Remix Culture allowed
✖ | Commercial Use
✖ | Free Cultural Works
✖ | Meets Open Definition

insert.stl

rubbercube.stl

topjoint.stl

innerfoot.stl

footrubber.stl

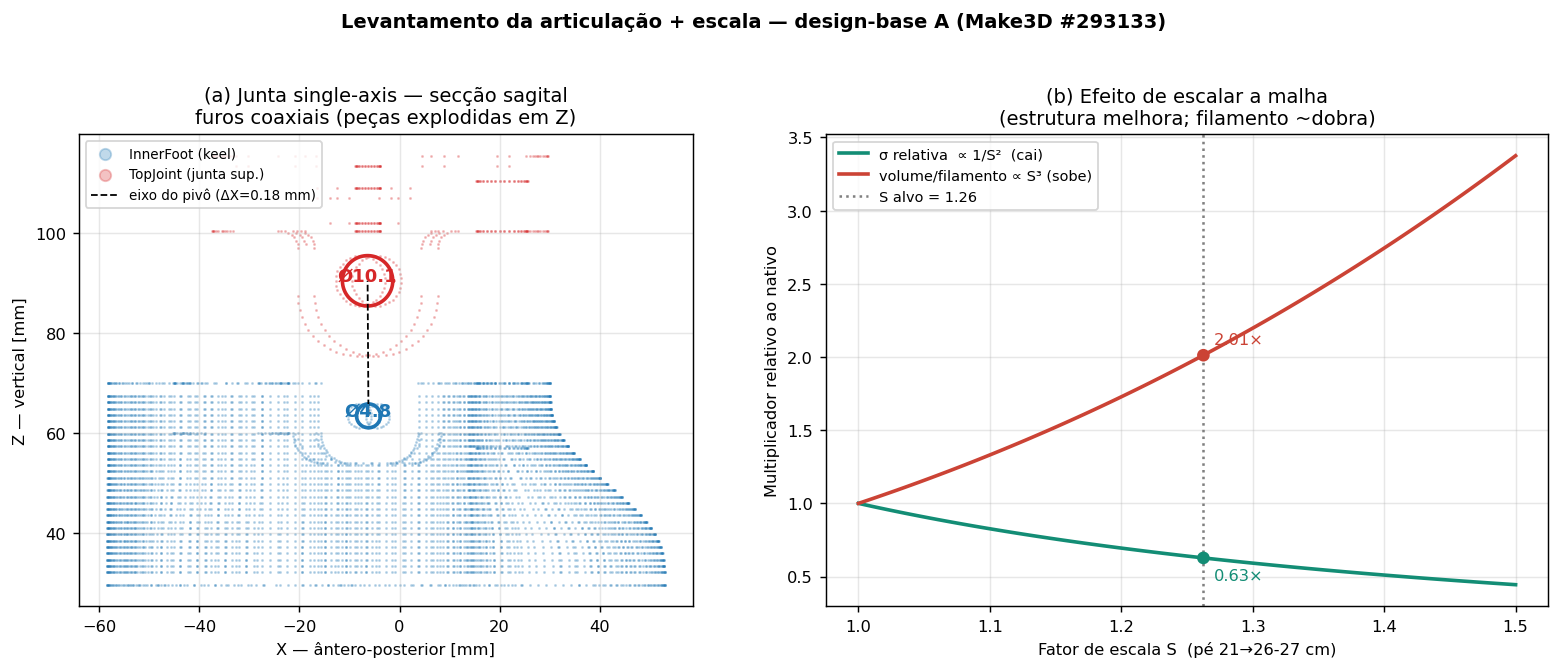
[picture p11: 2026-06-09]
cad/A_make3d_293133/medidas_articulacao.png

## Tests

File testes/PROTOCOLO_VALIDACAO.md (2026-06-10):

# Protocolo de validação — prótese pé-tornozelo

> Método definido **antes** dos testes (dia ~20/06) para não improvisar com a peça na mão.
> Objetivo: gerar os dados das seções 6 (validação) e 8 (discussão) do relatório, com
> registro fotográfico/vídeo para a apresentação. Validação **qualitativa/demonstrativa** —
> não é certificação de uso clínico.

---

## Teste 1 — Amplitude de movimento (ADM)

**Pergunta:** a articulação atinge a ADM-alvo? (dorsiflexão 10-15°, plantarflexão 15-20°)

**Material:** transferidor (ou app de medição de ângulo no celular — "Medir"/"Bubble Level"/"Clinometer"), marcador, câmera com tripé ou apoio fixo.

**Procedimento:**
1. Montar a junta (M8 + bucha + batentes TPU) e fixar o pylon/keel numa morsa ou apoio rígido, com a sola livre para girar.
2. Marcar com caneta uma linha de referência no keel (segmento da perna) e outra na sola (segmento do pé) — são os dois braços do ângulo.
3. **Posição neutra:** sola a 90° com o keel (pé plano). Fotografar de lado (plano sagital), câmera perpendicular ao eixo do pino. Anotar ângulo de referência.
4. **Dorsiflexão:** empurrar a ponta do pé para cima até o batente anterior travar. Fotografar. Medir o ângulo entre as duas marcas.
5. **Plantarflexão:** empurrar a ponta do pé para baixo até o batente posterior travar. Fotografar. Medir.
6. Repetir 3× cada movimento e medianar.

**Registro (`testes/adm.csv`):**
```
movimento,alvo_min,alvo_max,medido_1,medido_2,medido_3,mediana
dorsiflexao,10,15,,,,
plantarflexao,15,20,,,,
```

**Critério:** ✅ se a mediana cai dentro (ou próximo) da faixa-alvo. Se ficar fora, registrar e discutir na seção 8 (provável causa: dureza/geometria do batente TPU).

> ⚠ Fotografar **rigorosamente de lado**, com a câmera no nível do eixo do pino — ângulo de câmera enviesado falseia a leitura. App de ângulo no próprio plano da foto ajuda.

---

## Teste 2 — Carga estática

**Pergunta:** a peça suporta a carga de demonstração sem falhar?

> Carga de projeto = 1030 N (≈ 105 kgf, = 1,5×BW de 70 kg). Para um **teste seguro e
> demonstrativo**, NÃO é obrigatório chegar a 105 kgf — começar baixo e subir por degraus,
> observando. O objetivo é mostrar comportamento e ausência de falha catastrófica, não
> levar à ruptura.

**Material:** balança de banheiro (para conhecer a carga aplicada), peso conhecido OU prensa manual/morsa, apoio rígido, paquímetro ou régua, câmera.

**Opção A — carga por peso corporal (simples, demonstrativo):**
1. Apoiar a prótese montada na vertical, sola no chão, conector preso a um apoio rígido.
2. Aplicar carga gradual — pessoa apoiando peso parcial sobre a estrutura via o conector, com balança intermediária medindo quanto está sendo aplicado.
3. Subir em degraus: 20 → 40 → 60 → 80 kgf, fotografando cada degrau.
4. Observar e registrar: deformação visível? a junta cede? algum estalo/trinca?

**Opção B — carga por prensa/morsa (mais controlado):**
1. Posicionar a peça entre as garras com a carga alinhada ao eixo de aplicação real (vertical sobre o tornozelo).
2. Aplicar carga progressiva medindo com célula de carga ou estimando pelo aperto.
3. Mesma observação por degraus.

**Registro (`testes/carga.csv`):**
```
degrau_kgf,deformacao_observada,trinca,nota
20,,,
40,,,
60,,,
80,,,
```
+ medir, se possível, a **deflexão** (deslocamento da ponta do pé sob carga) com régua/paquímetro em cada degrau → permite comparar com o cálculo de flexão da seção 5.

**Critério:** ✅ se suporta a carga demonstrada sem falha estrutural nem deformação permanente. Registrar a carga máxima atingida com segurança (mesmo que abaixo de 105 kgf).

> ⚠ **Segurança:** carga sob estrutura impressa pode falhar de forma súbita e projetar fragmentos. Usar óculos de proteção, não posicionar o rosto sobre a peça, subir devagar. Parar ao primeiro sinal de trinca.

---

## Teste 3 — Funcional da junta (montagem)

**Checklist rápido na montagem (dia 19/06):**
- [ ] O parafuso M8 passa limpo pelo furo Ø8,4 do keel?
- [ ] A bucha nylon 10×8 assenta no bore Ø10 do tornozelo sem folga excessiva?
- [ ] A junta gira livre na ADM, sem travar nem ter folga lateral?
- [ ] Os batentes TPU limitam o movimento nos dois sentidos?
- [ ] Encaixe sola ↔ keel ↔ conector firme?

Se a folga do furo estiver errada (FDM real ≠ nominal): registrar o desvio e ajustar
(reimprimir keel com furo corrigido, ou bucha de espessura diferente).

---

## Entregáveis da validação (alimentam o relatório)

| Saída | Arquivo | Vai para |
|---|---|---|
| Dados de ADM | `testes/adm.csv` | Seção 6 |
| Dados de carga + deflexão | `testes/carga.csv` | Seção 6 + comparar c/ seção 5 |
| Fotos de cada teste | `fotos/` | Seção 6 + slides |
| Vídeo do ciclo de movimento | `fotos/` | Apresentação |
| Planilha de custo real | `testes/custo.csv` | Seção 7 |

> Com ADM e carga medidos, a **MINERVA Missão 2** analisa os dados e fecha as seções 6, 8 e 9.

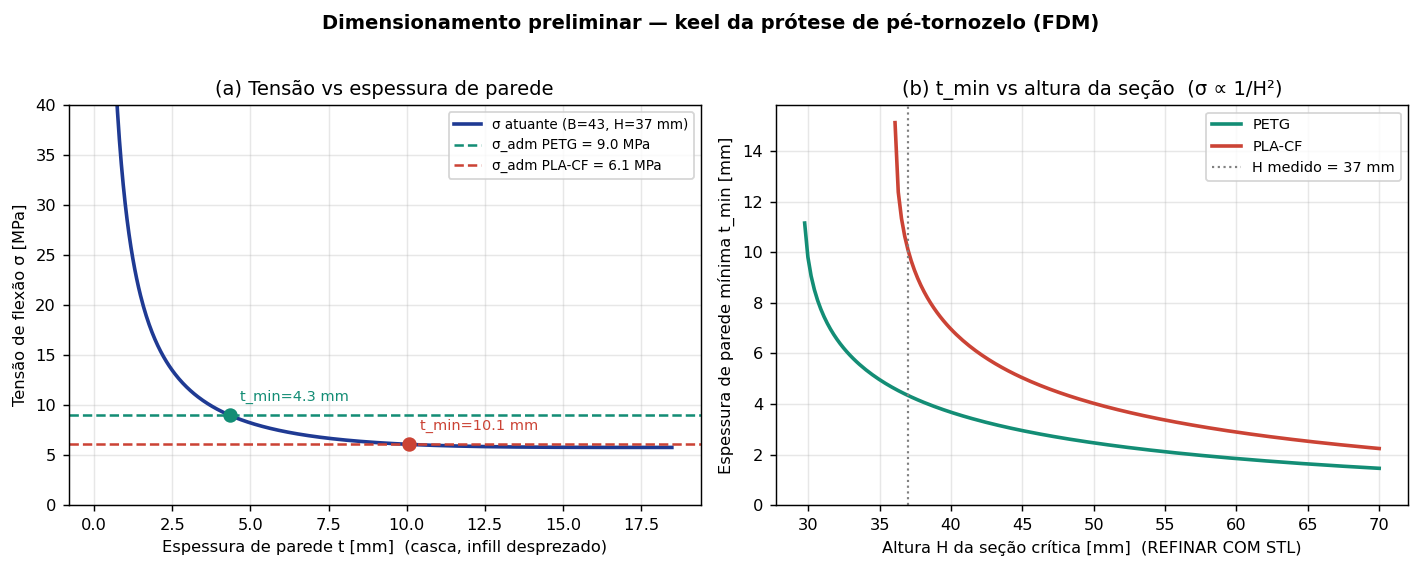
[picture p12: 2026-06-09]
testes/dimensionamento_flexao.png

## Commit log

2026-06-06 protese-tornozelo: esqueleto do projeto (README, relatório, plano, fontes)
    Trabalho de Dispositivos de Reabilitação (entrega 22/06): prótese funcional
    de pé-tornozelo single-axis, impressa em 3D, baixo custo. Decisões travadas:
    remix open-source, alvo adulto padrão, articulação single-axis. Inclui
    requisitos numéricos, régua de avaliação, candidatos open-source e cronograma.
2026-06-06 missão 1 completa: fundamentação biomecânica, requisitos, dimensionamento e matriz de decisão
2026-06-06 protese-tornozelo: adiciona ROADMAP visual com Gantt + árvore de tarefas
    Roadmap completo do projeto (06–22/06): diagrama Gantt Mermaid,
    árvore de tarefas por fase, grafo de dependências e tabela de status.
    Renderiza diretamente no GitHub.
2026-06-06 protese-tornozelo: adiciona candidatos D e E à matriz de decisão
    Printables #1032352 (PETG+TPU nativo, score 3,65) e #317213 Make3D
    Simple (CAD Fusion editável, score 3,75) como alternativas ao
    Appropedia (página fora do ar). Tabela comparativa atualizada com 5
    candidatos. A recomendação principal segue sendo o #293133 (score 4,2).
2026-06-07 protese-tornozelo: adiciona VOTACAO_DESIGN.md para decisão do grupo
    Relatório de votação com os 3 candidatos: custo estimado, materiais,
    articulação, prós/contras e tabela comparativa. Pronto para compartilhar.
2026-06-09 protese-tornozelo: trava design-base A (#293133), versiona STLs e re-roda dimensionamento com geometria medida
    - Decisao A (Make3D Printables #293133) registrada em README, ROADMAP, decisao_design_base e VOTACAO
    - STLs de A versionados em cad/A_make3d_293133/ + PDF em refs/
    - dimensionamento.py: geometria medida no InnerFoot.stl (B=43, H=37, L=55) substitui placeholder; SCALE explicito
    - RELATORIO 5.3 atualizado: PETG t_parede ~4,3mm, FS 2,5
    [InnerFoot.stl, Insert.stl, RubberCube.stl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]
2026-06-09 protese-tornozelo: adiciona Missao 1.5 (levantamento da articulacao + escala) para a MINERVA
2026-06-09 Missao 1.5: levantamento da articulacao single-axis + escala (design-base A)
    Mede a junta nos STLs nativos do Make3D #293133 (trimesh+numpy, reprodutivel)
    para alimentar o CAD. Cotas medidas, nao chutadas; cada uma com origem.
    Achados principais:
    - Pino NAO e M8: furo InnerFoot Ø4,8 (~M5) + bore TopJoint Ø10,0. Furos coaxiais
    (ΔX 0,18 mm; pecas explodidas em Z). Padronizar M8: abrir furo p/ Ø8,4 e usar
    o bore Ø10 nativo como assento de bucha nylon 10x8 (casa exato; bearing e o elo fraco).
    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
2026-06-09 protese-tornozelo: trava decisao pylon — Opcao A (Insert custom, grupo 09/06)
2026-06-09 Update README to remove safety warning
    Removed warning about academic demonstration device and safety concerns.
2026-06-10 Sincroniza STLs finais, especificacoes de impressao e script de processamento
    [batente_tpu.stl, conector_pylon_petg.stl, keel_petg.stl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]
2026-06-10 Sincroniza secao 1 + protocolo de validacao
